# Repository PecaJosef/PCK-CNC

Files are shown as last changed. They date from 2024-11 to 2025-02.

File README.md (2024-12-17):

# PCK-CNC
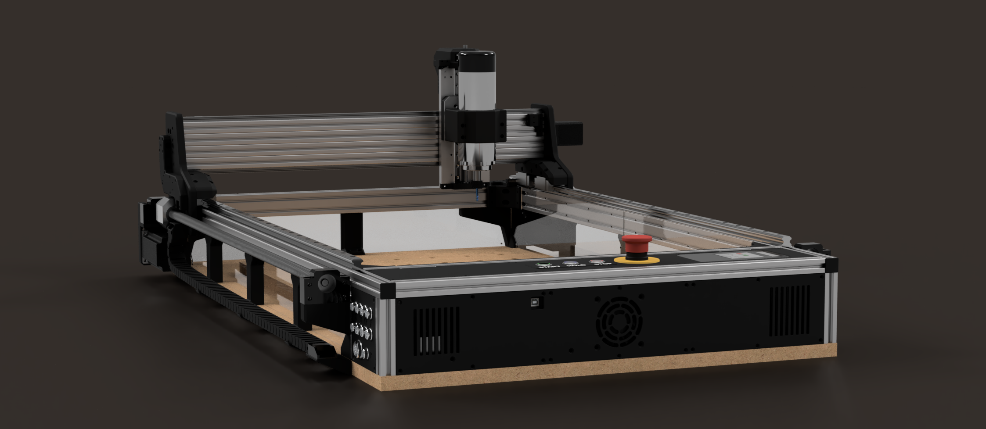
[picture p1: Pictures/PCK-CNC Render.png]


PCK-CNC is an open-source CNC router designed to offer precision, reliability, and affordability. This machine combines high-performance features with an accessible design that caters to both beginners and CNC hobbyists. Its structure is primarily 3D-printed, making it easy to build and modify, while critical components, such as aluminum parts, provide durability and strength. The router has a working area of 750mm x 490mm, making it versatile enough to handle a wide range of projects, from small hobbyist tasks to more professional-grade work.

To achieve good accuracy and reliability, the PCK-CNC utilizes ballscrews and linear rails, delivering superior precision compared to belt-driven systems. It is equipped with an 800W spindle, controlled by a Variable Frequency Drive (VFD), allowing precise adjustments to spindle speed based on the material and cutting requirements. The machine is capable of milling plastics, wood, and aluminum, ensuring it meets the needs of various users and applications.

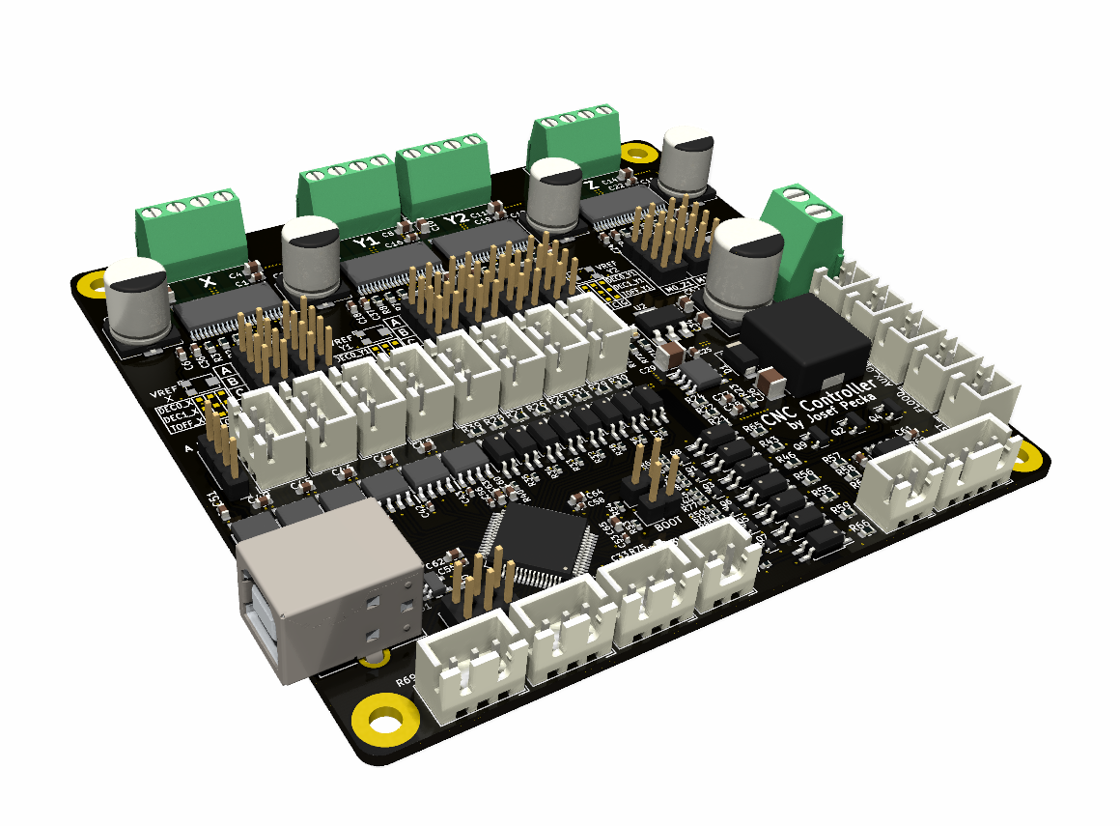
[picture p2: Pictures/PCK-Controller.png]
controller

The PCK-CNC features an integrated electronics system, saving space and making the setup more compact and user-friendly. At the heart of the system is the PCK Controller, an open-source controller designed specifically for this project. It is powered by a 32-bit microprocessor, offering smooth and fast operation, and runs on the open-source grblHAL firmware. This advanced software enables features like Y-axis auto-squaring, which improves repeatability and precision during machining.
The controller operates at 48V to manage higher motor speeds and directly interfaces with the VFD for spindle control. Safety and reliability are also priorities, the controller is galvanically isolated, protecting connected devices and computers from electrical faults. Additionally, it is designed to better withstand electromagnetic interference (EMI), ensuring stable and reliable operation.

One of the standout aspects of the PCK-CNC is its affordability. Despite its advanced features and capabilities, the machine can be built for approximately 1500 USD, making it an excellent choice for makers and hobbyists looking for a high-quality CNC router without a high price tag.
As an open-source project, PCK-CNC is open to collaboration and customization, inviting users to modify and enhance the design to suit their needs. Whether you’re starting your CNC journey or seeking a reliable platform for experimentation, the PCK-CNC provides an accessible and powerful solution for precise and efficient machining.

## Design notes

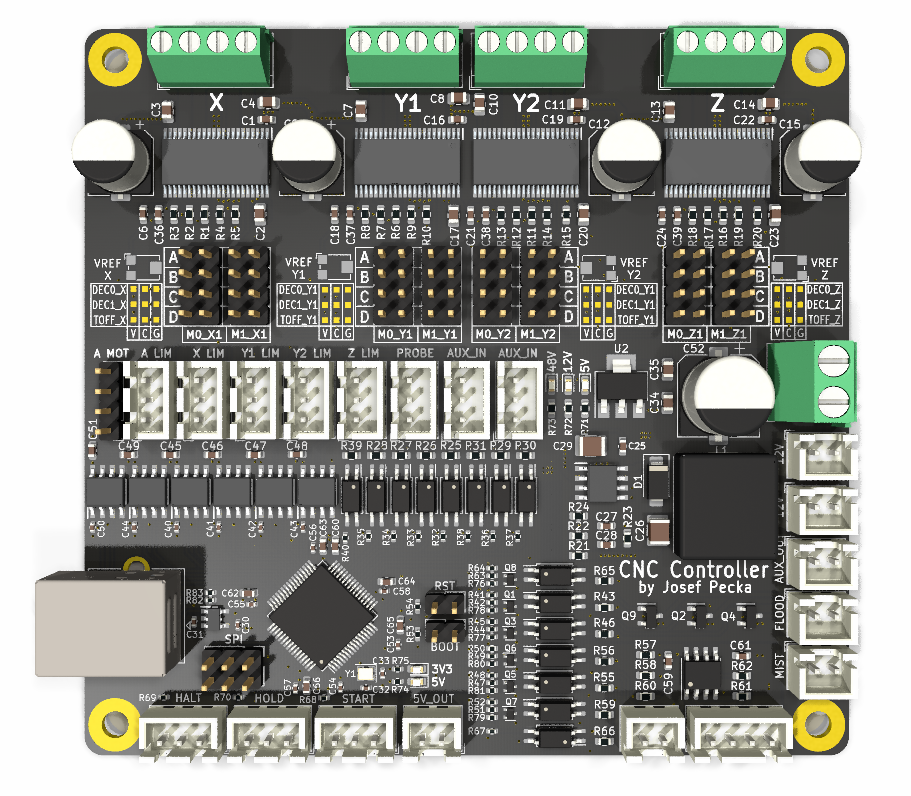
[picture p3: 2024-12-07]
Pictures/PCK-Controller top.png

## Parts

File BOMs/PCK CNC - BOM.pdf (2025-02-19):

Pcs | Extrusion size | Length | Sourcing
2 | 20x40mm | 1000mm | Best to source localy
2 | 20x40mm | 600mm
1 | 20x80mm | 670mm
1 | 20x20mm | 600mm
2 | 20x20mm | 95mm
2 | 20x20mm | 120mm
Pcs | Type | Model | Sourcing
2 | Nema 23 - 76mm | 23HE30-2804S | Stepper Online (https://www.omc-stepperonline.com/e-series-nema-23-bipolar-1-8deg-1-9nm-269oz-in-2-8a-3-2v-57x57x76mm-4-wires-23he30-2804s)
2 | Nema 17 - 48mm | 17HE19-2004S | Stepper Online (https://www.omc-stepperonline.com/e-series-nema-17-bipolar-55ncm-77-88oz-in-2a-42x48mm-4-wires-w-1m-cable-connector-17he19-2004s)
1 | Pulley GT2 60T | GT2 60T 6mm (8mm bore) | AliExpress (https://www.aliexpress.com/item/1005003165253849.html)
1 | Pulley GT2 20T | GT2 20T 6mm (5mm bore)
1 | Synchronous belt GT2 | GT2 6mm - 200mm
2 | Pulley T5 14T | T5 14T 15mm (6.35mm bore) | AliExpress (https://www.aliexpress.com/item/1005007828368485.html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)
2 | Pulley T5 14T | T5 14T 15mm (10mm bore) | AliExpress (https://www.aliexpress.com/item/1005007654749566.html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)
2 | Synchronous belt T5 | T5 15mm - 200mm | AliExpress (https://www.aliexpress.com/item/1005004695246594.html)
1 | Motor coupler | D19xL25 - 5mm - 8mm | AliExpress (https://www.aliexpress.com/item/1005004363938677.html)
Pcs | Type | Model | Sourcing
2 | Linear rail | HGR 15 - 1000mm | AliExpress (https://www.aliexpress.com/item/4000826413617.html)
4 | Linear rail block | HGH15CA
2 | Linear rail | MGN12 - 650mm | AliExpress (https://www.aliexpress.com/item/1000007480470.html)
2 | Linear rail block | MGN12H
2 | Linear rail | MGN9 - 200mm | AliExpress (https://www.aliexpress.com/item/1005002516956172.html)
4 | Linear rail block | MGN9C
2 | Ballscrew | SFU1605 - 1000mm | AliExpress (https://www.aliexpress.com/item/1005004452100727.html)
2 | Ball nut housing | DSG16H
2 | Ballscrew housing | BK12
2 | Ballscrew housing | BF12
1 | Ballscrew | SFU1204 - 650mm | AliExpress (https://www.aliexpress.com/item/1005005316105096.html)
1 | Ball nut housing | DSG12H
1 | Ballscrew housing | BK10
1 | Ballscrew housing | BF10
1 | Leadscrew - 2mm lead | T8 - 200mm | AliExpress (https://www.aliexpress.com/item/32507277503.html)
1 | Flat leadscrew nut | T8 nut | AliExpress (https://www.aliexpress.com/item/1005004574255316.html)
1 | Leadscrew housing | KFL08 8mm | AliExpress (https://www.aliexpress.com/item/1005002394517514.html)
1 | Bearing | 608ZZ | AliExpress (https://www.aliexpress.com/item/32435458212.html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)
Pcs | Type | Model | Sourcing
4 | Connector | GX12-4 | AliExpress (https://www.aliexpress.com/item/32716530720.html)
5 | Connector | GX12-2 | AliExpress (https://www.aliexpress.com/item/32716530720.html)
1 | Connector | GX20-4 | AliExpress (https://www.aliexpress.com/item/32716530720.html)
1 | Power socket | AC-04B | AliExpress (https://www.aliexpress.com/item/1005003010421047.html)
2 | Cable chain | 10x20mm - 1m | AliExpress (https://www.aliexpress.com/item/32999589537.html)
4 | Micro limit switch | KW11-3Z-B | AliExpress (https://www.aliexpress.com/item/1005006085607858.html?scm_id=1007.40050.354490.0&scm-url=1007.40050.354490.0)

Connectors & Wiring

Aluminum extrusions

Stepper motors & Belts, pulleys

Linear rails & Ballscrews, leadscrew

1 | Spindle cable | 4x1mm² (AWG20) - 3m | Best to source localy
1 | Stepper motor cables | 4x0.5mm² (AWG24) - 10m
1 | Limit switch cables | 3x0.25mm² (AWG30) - 10m
Pcs | Type | Model | Sourcing
1 | Spindle motor | VEVOR 800W - ER11 | AliExpress (https://www.aliexpress.com/item/1005007328434252.html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)
1 | VFD 1.5kW | A2-8015 | AliExpress (https://www.aliexpress.com/item/1005002865747373.html)
1 | PSU 600W 48V | LRS-600-48 | AliExpress (https://www.aliexpress.com/item/4000364274787.html)
3 | PCK Controller fan | 3010 - 12V | AliExpress (https://www.aliexpress.com/item/1005003102254928.html)
1 | Electronics fan | 7015 - 12V | AliExpress (https://www.aliexpress.com/item/1005004205974469.html)
1 | Emergency button | XB2-542 | AliExpress (https://www.aliexpress.com/item/1005001866043616.html?scm_id=1007.40050.354490.0&scm-url=1007.40050.354490.0)
3 | Button (Red,Green,Blue) | 19mm - 3-6V | AliExpress (https://www.aliexpress.com/item/1005003945292427.html)
1 | Contactor 230V 16A | 230V 16A - 2NO | AliExpress (https://www.aliexpress.com/item/4001172968682.html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)
4 | Heatsink (for PCK Controller) | 22x22x15 mm | AliExpress (https://www.aliexpress.com/item/1005004724669234.html)
Pcs | Size | Type | Sourcing
8 | M2.5x16 mm | Flat head
92 | M3x5 mm | Round head
67 | M3x8 mm | Flat head
26 | M3x8 mm | Socket head
48 | M3x10 mm | Flat head
14 | M3x10 mm | Socket head
2 | M3x12 mm | Flat head
15 | M3x16 mm | Flat head
6 | M3x20 mm | Socket head
12 | M3x25 mm | Flat head
6 | M4x6 mm | Flat head
18 | M4x8 mm | Socket head
12 | M4x10 mm | Flat head
20 | M4x10 mm | Socket head
58 | M4x12 mm | Socket head
4 | M4x16 mm | Flat head
16 | M4x16 mm | Socket head
4 | M4x20 mm | Flat head
18 | M4x40 mm | Socket head
6 | M5x8 mm | Flat head
8 | M5x10 mm | Flat head
4 | M5x20 mm | Socket head
12 | M5x25 mm | Socket head
4 | M5x30 mm | Socket head
20 | M5x50 mm | Socket head
4 | M6x70 mm | Socket head
32 | 3x20 mm wood screw | Flat head
13 | 4x20 mm wood screw | Flat head
4 | M2.5 Nut | Standart
8 | M3 Nut | Standart
16 | M4 Nut | Standart
32 | M5 Nut | Standart

Best to source localy

Electronics

Screws & nuts

4 | M6 Nut | Standart
140 | M3 T-Slot nut | 20mm Series | AliExpress (https://www.aliexpress.com/item/1005004060299402.html)
76 | M4 T-Slot nut | 20mm Series | AliExpress (https://www.aliexpress.com/item/1005004060299402.html)
42 | M3 Threaded insert | Length - 5mm | AliExpress (https://www.aliexpress.com/item/32958273559.html)
8 | M4 Threaded insert | Length - 5mm | AliExpress (https://www.aliexpress.com/item/32958273559.html)
Pcs | File name | Material | Manufacturing
2 | Acrylic sheet REAR | Acrylic | Laser/Milling
4 | Acrylic sheet SIDE | Acrylic | Laser/Milling
2 | Base mount FRONT | Aluminum | Laser/Milling
2 | Base mount rear | Aluminum | Laser/Milling
1 | Spindle mount plate | Aluminum | Milling
1 | X Axis plate LEFT | Aluminum | Milling
1 | X Axis plate RIGHT | Aluminum | Milling
1 | Z Axis back plate | Aluminum | Milling
1 | Z Axis plate | Aluminum | Milling
1 | Base mount FRONT L | PETG | 3D Printing
1 | Base mount FRONT R | PETG | 3D Printing
4 | Base mount nut cap | PLA, PETG | 3D Printing
6 | Base support | PETG | 3D Printing
1 | Cable cover | PLA, PETG | 3D Printing
1 | Control panel label | PLA, PETG | 3D Printing
9 | Electronics panel connector A | PLA, PETG | 3D Printing
7 | Electronics panel connector B | PLA, PETG | 3D Printing
1 | Electronics panel connector C | PLA, PETG | 3D Printing
16 | Electronics panel corner connector | PLA, PETG | 3D Printing
1 | Electronics panel FRONT L | PLA, PETG | 3D Printing
1 | Electronics panel FRONT M | PLA, PETG | 3D Printing
1 | Electronics panel FRONT R | PLA, PETG | 3D Printing
1 | Electronics panel LEFT | PLA, PETG | 3D Printing
1 | Electronics panel REAR L | PLA, PETG | 3D Printing
1 | Electronics panel REAR R | PLA, PETG | 3D Printing
1 | Electronics panel RIGHT | PLA, PETG | 3D Printing
1 | Electronics panel TOP L | PLA, PETG | 3D Printing
1 | Electronics panel TOP M | PLA, PETG | 3D Printing
1 | Electronics panel TOP R | PLA, PETG | 3D Printing
4 | Frame corner connector | PETG | 3D Printing
1 | PCK CNC Controller mount | PLA, PETG | 3D Printing
1 | PSU Mounting plate A | PLA, PETG | 3D Printing
1 | PSU Mounting plate B | PLA, PETG | 3D Printing
1 | PSu Mounting plate BOT | PLA, PETG | 3D Printing
1 | Spindle mount | PETG | 3D Printing
1 | X Axis ballscrew mount LEFT | PETG | 3D Printing
1 | X Axis ballscrew mount RIGHT | PETG | 3D Printing
1 | X Axis cable chain mount | PLA, PETG | 3D Printing
1 | X Axis cable chain support | PLA, PETG | 3D Printing
1 | X Axis end stop mount | PLA, PETG | 3D Printing
1 | X Axis linear rail mount | PETG | 3D Printing
1 | X Axis motor mount | PETG | 3D Printing

Mechanical parts

1 | Y Axis cable chain mount B | PLA, PETG | 3D Printing
1 | Y Axis cable chain mount F | PLA, PETG | 3D Printing
3 | Y Axis cable chain support | PLA, PETG | 3D Printing
1 | Y Axis end stop mount LEFT | PLA, PETG | 3D Printing
1 | Y Axis end stop mount RIGHT | PLA, PETG | 3D Printing
1 | Y Axis linear rail mount LEFT | PETG | 3D Printing
1 | Y Axis linear rail mount RIGHT | PETG | 3D Printing
1 | Y Axis motor mount LEFT | PETG | 3D Printing
1 | Y Axis motor mount RIGHT | PETG | 3D Printing
1 | Z Axis cover | PLA, PETG | 3D Printing
1 | Z Axis endstop mount | PLA, PETG | 3D Printing
1 | Z Axis leadscrew bearing mount TOP | PETG | 3D Printing
1 | Z Axis leadscrew bearing mount | PETG | 3D Printing
1 | Z Axis linear rails mount | PETG | 3D Printing
1 | Z Axis motor holder | PETG | 3D Printing
Pcs | File name | Size | Sourcing
1 | MDF Base board | 1125x640x20mm | Best to source localy
1 | MDF Spoil board | 760x490x18mm

MDF Boards

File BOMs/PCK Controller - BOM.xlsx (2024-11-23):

Item | Qty | Reference(s) | Value | LibPart | Footprint | Datasheet | DNP | Description | Height | Manufacturer_Name | Manufacturer_Part_Number | Mouser Part Number | Mouser Price/Stock | Sim.Device | Sim.Pins
1 | 7 | 12V1, 12V2, AUX1, ESTOP1, FLOOD1, MIST1, PWR1 | Conn_01x02 | Connector_Generic:Conn_01x02 | Connector_JST:JST_XH_B2B-XH-A_1x02_P2.50mm_Vertical | ~
2 | 1 | A_LIM1 | A_Lim | Connector_Generic:Conn_01x03 | Connector_JST:JST_XH_B3B-XH-A_1x03_P2.50mm_Vertical | ~
3 | 1 | AUX_IN1 | ESTOP | Connector_Generic:Conn_01x03 | Connector_JST:JST_XH_B3B-XH-A_1x03_P2.50mm_Vertical | ~
4 | 1 | AUX_IN2 | Door | Connector_Generic:Conn_01x03 | Connector_JST:JST_XH_B3B-XH-A_1x03_P2.50mm_Vertical | ~
5 | 1 | BOOT1 | BOOT | Connector_Generic:Conn_01x02 | Connector_PinHeader_2.54mm:PinHeader_1x02_P2.54mm_Vertical | ~
6 | 5 | C1, C16, C19, C22, C61 | 1uF/16V | Device:C | Capacitor_SMD:C_0603_1608Metric | ~
7 | 4 | C2, C17, C20, C23 | 0.1uF/63V | Device:C | Capacitor_SMD:C_0805_2012Metric | ~
8 | 2 | C3, C4 | 10nF/63V | Device:C | Capacitor_SMD:C_0805_2012Metric | ~
9 | 4 | C5, C9, C12, C15 | 47uF/63V | Device:C_Polarized | Capacitor_SMD:CP_Elec_8x10 | ~
10 | 4 | C6, C18, C21, C24 | 1uF/6.3V | Device:C | Capacitor_SMD:C_0603_1608Metric | ~
11 | 6 | C7, C8, C10, C11, C13, C14 | 0.01uF/63V | Device:C | Capacitor_SMD:C_0805_2012Metric | ~
12 | 1 | C25 | 100nF/10V | Device:C | Capacitor_SMD:C_0603_1608Metric | ~
13 | 1 | C26 | 47uF/25V | Device:C | Capacitor_SMD:C_1210_3225Metric | ~
14 | 1 | C27 | 100pF | Device:C | Capacitor_SMD:C_0603_1608Metric | ~
15 | 1 | C28 | 15nF | Device:C | Capacitor_SMD:C_0603_1608Metric | ~
16 | 1 | C29 | 2.2uF/63V | Device:C | Capacitor_SMD:C_1210_3225Metric | ~
17 | 2 | C30, C31 | 1uF/6.3V | Device:C | Capacitor_SMD:C_0402_1005Metric | ~
18 | 2 | C32, C33 | 10pF | Device:C | Capacitor_SMD:C_0402_1005Metric | ~
19 | 1 | C34 | 10uF/25V | Device:C | Capacitor_SMD:C_0805_2012Metric | ~
20 | 1 | C35 | 10uF/10V | Device:C | Capacitor_SMD:C_0805_2012Metric | ~
21 | 4 | C36, C37, C38, C39 | 0.1uF/10V | Device:C | Capacitor_SMD:C_0603_1608Metric | ~
22 | 6 | C40, C41, C42, C43, C44, C50 | 0.1uF/6.3V | Device:C | Capacitor_SMD:C_0402_1005Metric | ~
23 | 6 | C45, C46, C47, C48, C49, C51 | 0.1uF/6.3V | Device:C | Capacitor_SMD:C_0603_1608Metric | ~
24 | 1 | C52 | 100u/63V | Device:C_Polarized | Capacitor_SMD:CP_Elec_10x12.5 | ~
25 | 6 | C53, C54, C55, C56, C57, C58 | 100n | Device:C | Capacitor_SMD:C_0402_1005Metric | ~
26 | 1 | C59 | 1u/16V | Device:C | Capacitor_SMD:C_0603_1608Metric | ~
27 | 1 | C60 | 4.7uF/6.3V | Device:C | Capacitor_SMD:C_0603_1608Metric | ~
28 | 5 | C62, C63, C64, C65, C66 | 1u | Device:C | Capacitor_SMD:C_0603_1608Metric | ~
29 | 1 | D1 | 3.5A | Device:D | Diode_SMD:D_SMA | ~ |  |  |  |  |  |  |  | D | 1=K 2=A
30 | 5 | D2, D3, D4, D5, D6 | LED | Device:LED | LED_SMD:LED_0603_1608Metric | ~
31 | 4 | H1, H2, H3, H4 | MountingHole_Pad | Mechanical:MountingHole_Pad | MountingHole:MountingHole_3.5mm_Pad | ~
32 | 4 | IC1, IC2, IC3, IC4 | DRV8462DDWR_X | SamacSys_Parts:DRV8462DDWR | SamacSys_Parts:SOP64P810X120-45N | https://www.ti.com/lit/gpn/drv8462 |  | Motor / Motion / Ignition Controllers & Drivers 65-V, 10-A, dual H-bridge stepper motor driver with smart tune, stall detect and auto-torque | 2024-02-01 | Texas Instruments | DRV8462DDWR | 595-DRV8462DDWR | https://www.mouser.co.uk/ProductDetail/Texas-Instruments/DRV8462DDWR?qs=rQFj71Wb1eVexvYNsDfnvA%3D%3D
33 | 1 | IC5 | TPS54360BDDAR | SamacSys_Parts:TPS54360BDDAR | SamacSys_Parts:SOIC127P600X170-9N | http://www.ti.com/lit/gpn/TPS54360B |  | 60-V input, 3.5-A, step-down DC/DC converter with Eco-Mode | 2024-07-01 | Texas Instruments | TPS54360BDDAR | 595-TPS54360BDDAR | https://www.mouser.co.uk/ProductDetail/Texas-Instruments/TPS54360BDDAR?qs=l7cgNqFNU1iKlQpZ394odQ%3D%3D
34 | 6 | IC6, IC7, IC8, IC9, IC10, IC12 | ISO6720FBDR | SamacSys_Parts:ISO6720FBDR | SamacSys_Parts:SOIC127P600X175-8N | https://www.ti.com/lit/ds/symlink/iso6720.pdf?ts=1631770491208 |  | Digital Isolators General purpose dual-channel, 2/0, digital isolator | 1975-01-01 | Texas Instruments | ISO6720FBDR | 595-ISO6720FBDR | https://www.mouser.co.uk/ProductDetail/Texas-Instruments/ISO6720FBDR?qs=QNEnbhJQKva93m6DsjFZMw%3D%3D
35 | 1 | IC11 | TLV75533PDBVR | SamacSys_Parts:TLV75533PDBVR | SamacSys_Parts:SOT95P280X145-5N | http://www.ti.com/lit/gpn/tlv755p |  | LDO Voltage Regulators 500-mA, Low IQ, Small Size, Low Dropout Regulator 5-SOT-23 -40 to 125 | 1945-01-01 | Texas Instruments | TLV75533PDBVR | 595-TLV75533PDBVR | https://www.mouser.co.uk/ProductDetail/Texas-Instruments/TLV75533PDBVR?qs=55YtniHzbhAKEwqeO2xJXQ%3D%3D
36 | 1 | J1 | 48V_IN | Connector:Screw_Terminal_01x02 | TerminalBlock_Phoenix:TerminalBlock_Phoenix_MKDS-1,5-2_1x02_P5.00mm_Horizontal | ~
37 | 1 | J2 | Conn_01x04 | Connector_Generic:Conn_01x04 | Connector_JST:JST_XH_B4B-XH-A_1x04_P2.50mm_Vertical | (symbol "Connector_Generic:Conn_01x04" (pin_names (offset 1.016) hide) (in_bom yes) (on_board yes)
38 | 4 | J3, J19, J30, J41 | TOFF_VCC | Connector:Conn_01x01_Pin | PADs:Pad_0.75x0.75mm_borderless | ~
39 | 4 | J4, J20, J31, J42 | TOFF_COM | Connector:Conn_01x01_Pin | PADs:Pad_0.75x0.75mm_borderless | ~
40 | 4 | J5, J21, J32, J43 | TOFF_GND | Connector:Conn_01x01_Pin | PADs:Pad_0.75x0.75mm_borderless | ~
41 | 4 | J6, J7, J8, J9 | Screw_Terminal_01x04 | Connector:Screw_Terminal_01x04 | TerminalBlock_4Ucon:TerminalBlock_4Ucon_1x04_P3.50mm_Horizontal | ~
42 | 4 | J10, J22, J33, J44 | DEC0_VCC | Connector:Conn_01x01_Pin | PADs:Pad_0.75x0.75mm_borderless | ~
43 | 4 | J11, J23, J34, J45 | DEC0_COM | Connector:Conn_01x01_Pin | PADs:Pad_0.75x0.75mm_borderless | ~
44 | 4 | J12, J24, J35, J46 | DEC0_GND | Connector:Conn_01x01_Pin | PADs:Pad_0.75x0.75mm_borderless | ~
45 | 4 | J13, J25, J36, J47 | DEC1_VCC | Connector:Conn_01x01_Pin | PADs:Pad_0.75x0.75mm_borderless | ~
46 | 4 | J14, J26, J37, J48 | DEC1_COM | Connector:Conn_01x01_Pin | PADs:Pad_0.75x0.75mm_borderless | ~
47 | 4 | J15, J27, J38, J49 | DEC1_GND | Connector:Conn_01x01_Pin | PADs:Pad_0.75x0.75mm_borderless | ~
48 | 1 | J16 | Conn_01x04 | Connector_Generic:Conn_01x04 | Connector_PinHeader_2.54mm:PinHeader_1x04_P2.54mm_Vertical | ~
49 | 1 | J18 | Conn_01x06 | Connector_Generic:Conn_01x06 | Connector_PinHeader_2.54mm:PinHeader_2x03_P2.54mm_Vertical | ~
50 | 1 | L1 | 22uH | Device:L | Inductor_SMD:L_12x12mm_H8mm | ~
51 | 4 | M0_X1, M0_Y1, M0_Y2, M0_Z1 | M0 | Connector_Generic:Conn_02x04_Odd_Even | Connector_PinHeader_2.54mm:PinHeader_2x04_P2.54mm_Vertical | ~
52 | 4 | M1_X1, M1_Y1, M1_Y2, M1_Z1 | M1 | Connector_Generic:Conn_02x04_Odd_Even | Connector_PinHeader_2.54mm:PinHeader_2x04_P2.54mm_Vertical | ~
53 | 1 | PAUSE1 | Pause | Connector_Generic:Conn_01x03 | Connector_JST:JST_XH_B3B-XH-A_1x03_P2.50mm_Vertical | ~
54 | 1 | PROBE1 | Probe | Connector_Generic:Conn_01x03 | Connector_JST:JST_XH_B3B-XH-A_1x03_P2.50mm_Vertical | ~
55 | 6 | Q1, Q3, Q5, Q6, Q7, Q8 | DMG1012T | Transistor_FET:DMG1012T | Package_TO_SOT_SMD:SOT-523 | https://www.diodes.com/assets/Datasheets/ds31783.pdf
56 | 3 | Q2, Q4, Q9 | DMN6075S | Transistor_FET:DMN6075S | Package_TO_SOT_SMD:SOT-23 | http://www.diodes.com/assets/Datasheets/DMN6075S.pdf
57 | 1 | R0 | 0R | Device:R | Resistor_SMD:R_0603_1608Metric | ~
58 | 19 | R1, R2, R3, R6, R7, R8, R11, R12, R13, R16, R17, R18, R22, R43, R46, R57, R58, R61, R65 | 10k | Device:R | Resistor_SMD:R_0603_1608Metric | ~
59 | 8 | R4, R5, R9, R10, R14, R15, R19, R20 | 330k | Device:R | Resistor_SMD:R_0603_1608Metric | ~
60 | 1 | R21 | 140k | Device:R | Resistor_SMD:R_0603_1608Metric | ~
61 | 1 | R23 | 12,1k | Device:R | Resistor_SMD:R_0603_1608Metric | ~
62 | 1 | R24 | 187k | Device:R | Resistor_SMD:R_0603_1608Metric | ~
63 | 10 | R25, R26, R27, R28, R29, R30, R31, R39, R66, R71 | 1k | Device:R | Resistor_SMD:R_0603_1608Metric | ~
64 | 17 | R32, R33, R34, R35, R36, R37, R38, R40, R67, R74, R75, R76, R77, R78, R79, R80, R81 | 1k | Device:R | Resistor_SMD:R_0402_1005Metric | ~
65 | 6 | R41, R45, R48, R50, R52, R64 | 470R | Device:R | Resistor_SMD:R_0402_1005Metric | ~
66 | 9 | R42, R44, R47, R49, R51, R63, R68, R69, R70 | 10k | Device:R | Resistor_SMD:R_0402_1005Metric | ~
67 | 2 | R53, R54 | 10k | Device:R | Resistor_SMD:R_0402_1005Metric_Pad0.72x0.64mm_HandSolder | ~
68 | 2 | R55, R56 | 1K | Device:R | Resistor_SMD:R_0603_1608Metric | ~
69 | 3 | R59, R60, R72 | 4k7 | Device:R | Resistor_SMD:R_0603_1608Metric | ~
70 | 1 | R62 | 100k | Device:R | Resistor_SMD:R_0603_1608Metric | ~
71 | 1 | R73 | 22k (10k) | Device:R | Resistor_SMD:R_0603_1608Metric | ~
72 | 2 | R82, R83 | 22R | Device:R | Resistor_SMD:R_0402_1005Metric | ~
73 | 1 | RST1 | RST | Connector_Generic:Conn_01x02 | Connector_PinHeader_2.54mm:PinHeader_1x02_P2.54mm_Vertical | ~
74 | 4 | RV1, RV2, RV3, RV4 | 30k | Device:R_Potentiometer | Potentiometer_SMD:Potentiometer_Bourns_TC33X_Vertical | ~
75 | 1 | START1 | Start | Connector_Generic:Conn_01x03 | Connector_JST:JST_XH_B3B-XH-A_1x03_P2.50mm_Vertical | ~
76 | 1 | STOP1 | Stop | Connector_Generic:Conn_01x03 | Connector_JST:JST_XH_B3B-XH-A_1x03_P2.50mm_Vertical | ~
77 | 1 | U1 | STM32F446RETx | MCU_ST_STM32F4:STM32F446RETx | Package_QFP:LQFP-64_10x10mm_P0.5mm | https://www.st.com/resource/en/datasheet/stm32f446re.pdf
78 | 1 | U2 | NCP1117-5.0_SOT223 | Regulator_Linear:NCP1117-5.0_SOT223 | Package_TO_SOT_SMD:SOT-223-3_TabPin2 | http://www.onsemi.com/pub_link/Collateral/NCP1117-D.PDF
79 | 15 | U3, U4, U5, U6, U7, U8, U9, U10, U12, U13, U14, U15, U16, U17, U18 | TLP293 | Isolator:TLP291 | Package_SO:SOIC-4_4.55x2.6mm_P1.27mm | https://toshiba.semicon-storage.com/info/docget.jsp?did=12884&prodName=TLP291
80 | 1 | U11 | LM358 | Amplifier_Operational:LM358 | Package_SO:SOIC-8_3.9x4.9mm_P1.27mm | http://www.ti.com/lit/ds/symlink/lm2904-n.pdf
81 | 1 | USB1 | USB_B | Connector:USB_B | NEW_USB:USB_B_OST_USB-B1HSxx_Horizontal_NEW | ~
82 | 1 | X_LIM1 | X_Lim | Connector_Generic:Conn_01x03 | Connector_JST:JST_XH_B3B-XH-A_1x03_P2.50mm_Vertical | ~
83 | 1 | Y1 | 25MHz/10pF | Device:Crystal_GND24 | Crystal:Crystal_SMD_2016-4Pin_2.0x1.6mm | ~
84 | 1 | Y1_LIM1 | Y1_Lim | Connector_Generic:Conn_01x03 | Connector_JST:JST_XH_B3B-XH-A_1x03_P2.50mm_Vertical | ~
85 | 1 | Y2_LIM1 | Y2_Lim | Connector_Generic:Conn_01x03 | Connector_JST:JST_XH_B3B-XH-A_1x03_P2.50mm_Vertical | ~
86 | 1 | Z_LIM1 | Z_Lim | Connector_Generic:Conn_01x03 | Connector_JST:JST_XH_B3B-XH-A_1x03_P2.50mm_Vertical | ~

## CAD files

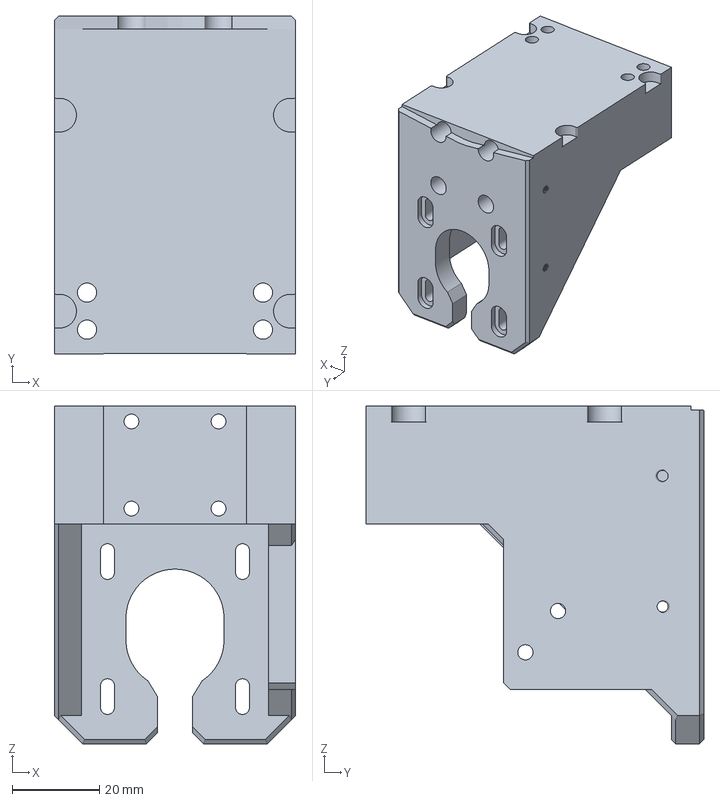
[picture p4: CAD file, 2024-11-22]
3D Printed parts/3MF Files/Z Axis motor holder.3mf
55.4 x 77.6 x 77.5 mm

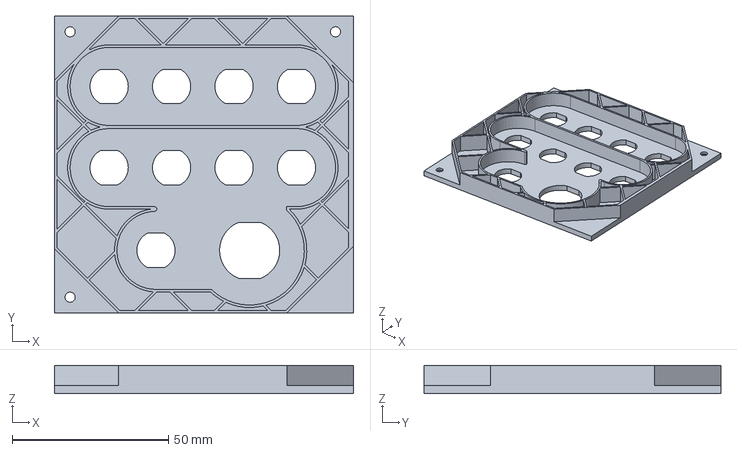
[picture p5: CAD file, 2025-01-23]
3D Printed parts/STEP Files/Electronics panel LEFT.step
95.8 x 95.0 x 9.00 mm

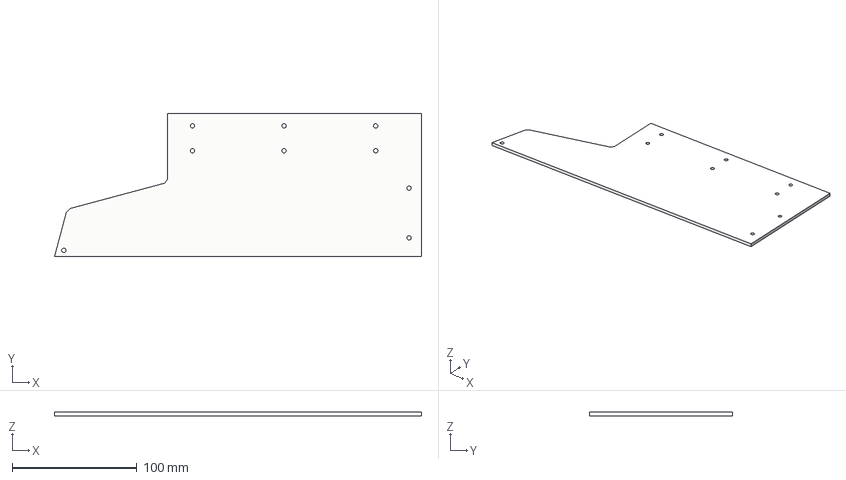
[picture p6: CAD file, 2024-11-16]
Acrylic sheets/STEP Files/Acrylic sheet REAR.step
294.8 x 115.0 x 3.00 mm

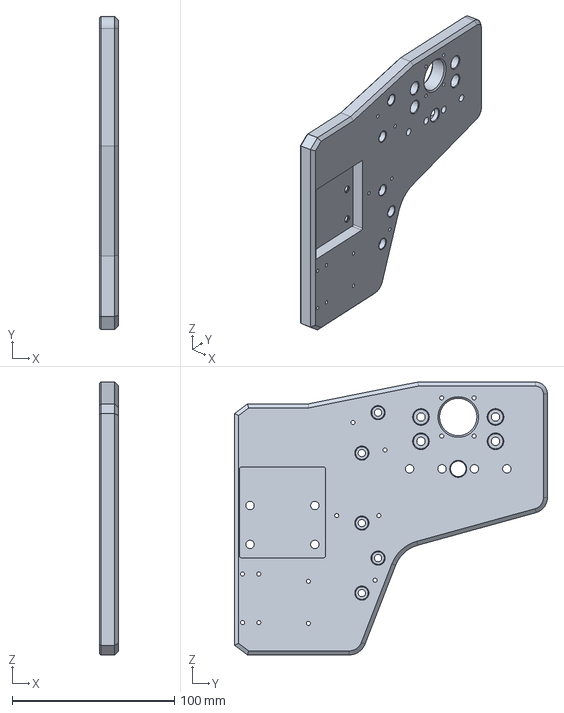
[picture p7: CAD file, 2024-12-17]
Aluminum parts/STEP Files/X Axis plate LEFT.step
12.0 x 193.2 x 168.5 mm

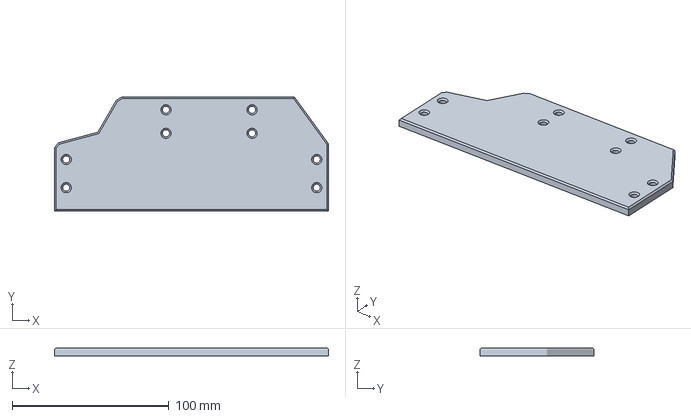
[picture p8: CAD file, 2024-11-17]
3D Printed parts/3MF Files/PSU Mounting plate B.3mf
175.0 x 73.0 x 5.25 mm

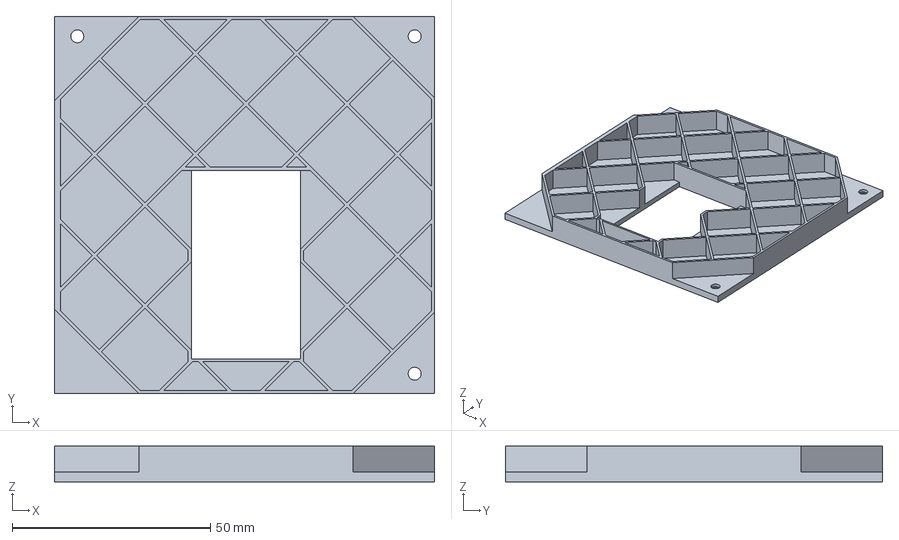
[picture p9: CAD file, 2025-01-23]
3D Printed parts/STEP Files/Electronics panel RIGHT.step
95.8 x 95.0 x 9.00 mm

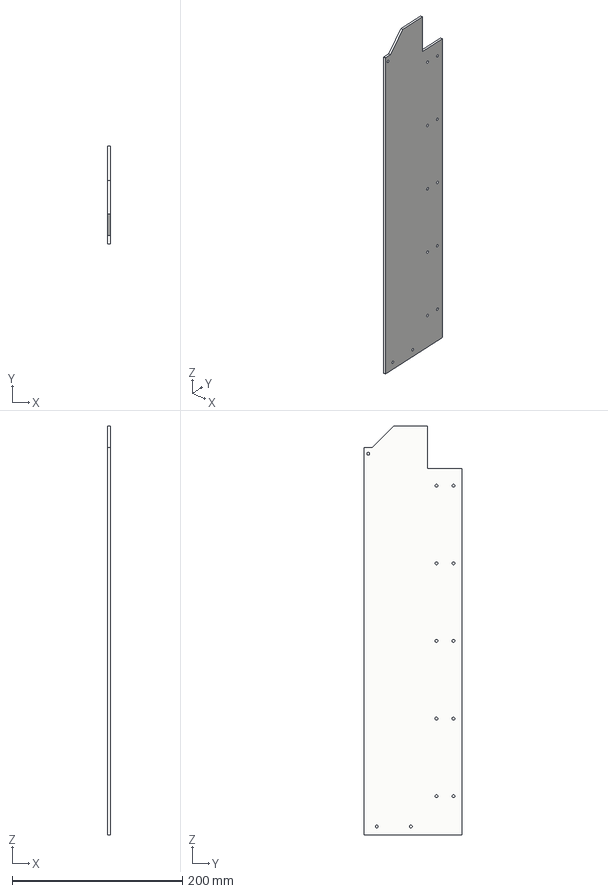
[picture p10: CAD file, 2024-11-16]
Acrylic sheets/STEP Files/Acrylic sheet SIDE.step
3.00 x 115.0 x 479.8 mm

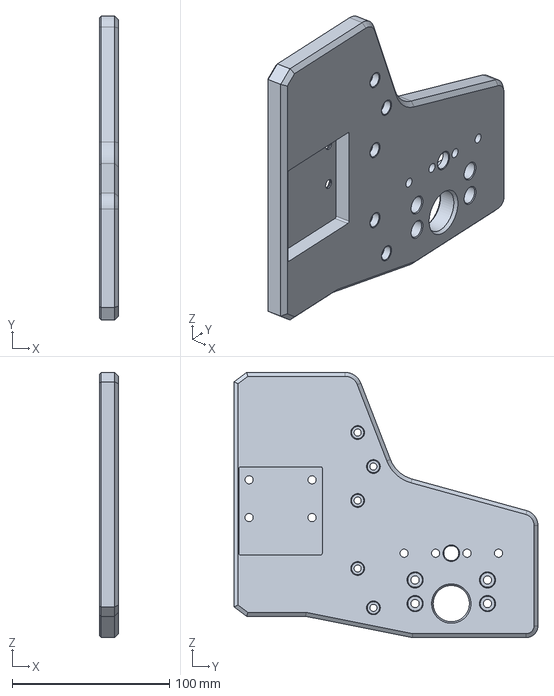
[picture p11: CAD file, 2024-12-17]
Aluminum parts/STEP Files/X Axis plate RIGHT.step
12.0 x 193.2 x 168.5 mm

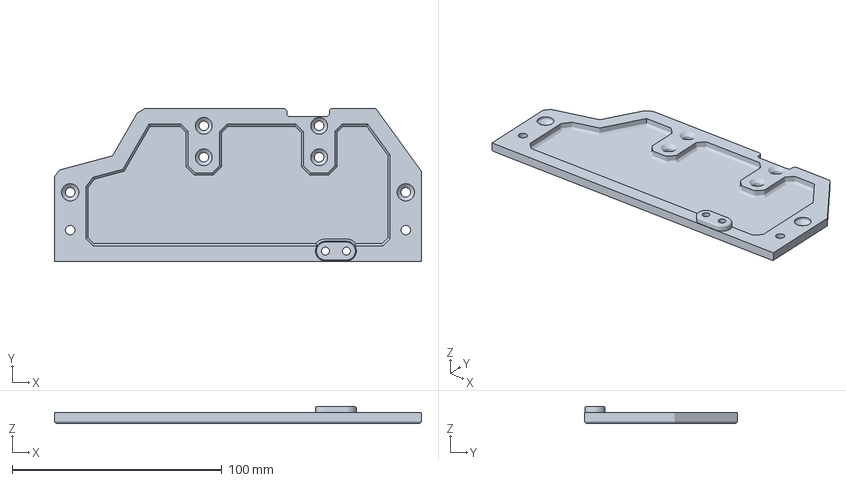
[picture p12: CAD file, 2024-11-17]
3D Printed parts/3MF Files/PSU Mounting plate A.3mf
175.0 x 73.0 x 8.25 mm

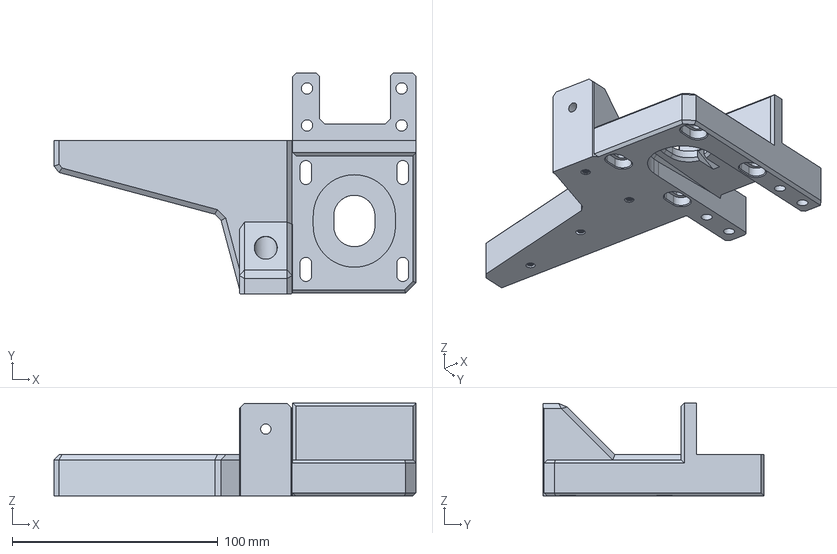
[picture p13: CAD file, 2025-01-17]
3D Printed parts/STEP Files/Y Axis motor mount RIGHT.step
176.1 x 107.5 x 45.1 mm

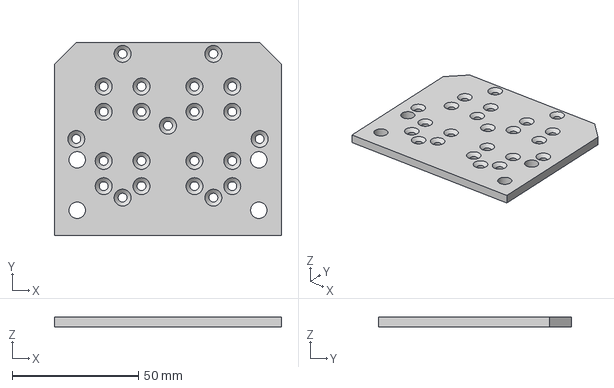
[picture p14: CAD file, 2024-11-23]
Aluminum parts/STEP Files/Spindle mount plate.step
90.0 x 76.5 x 4.00 mm

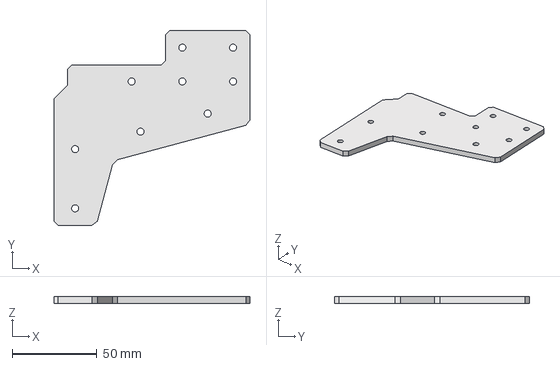
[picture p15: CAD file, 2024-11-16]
Aluminum parts/STEP Files/Base mount FRONT.step
115.9 x 115.0 x 4.00 mm

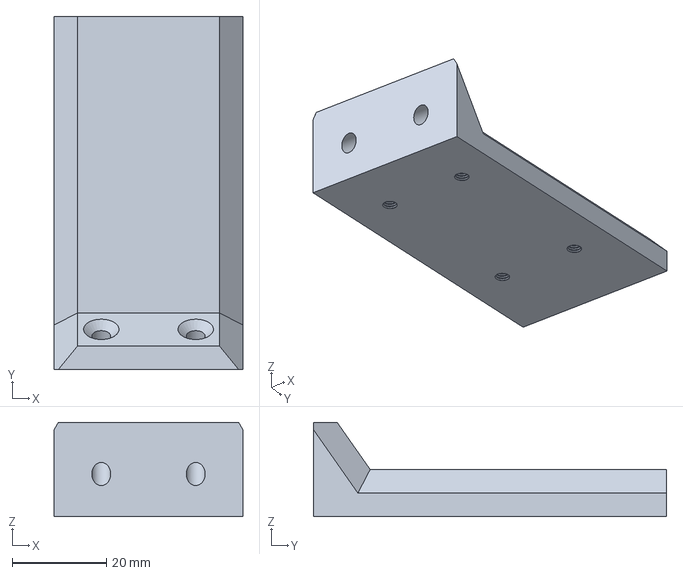
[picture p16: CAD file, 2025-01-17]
3D Printed parts/STEP Files/Base support REAR.step
40.0 x 74.8 x 20.0 mm

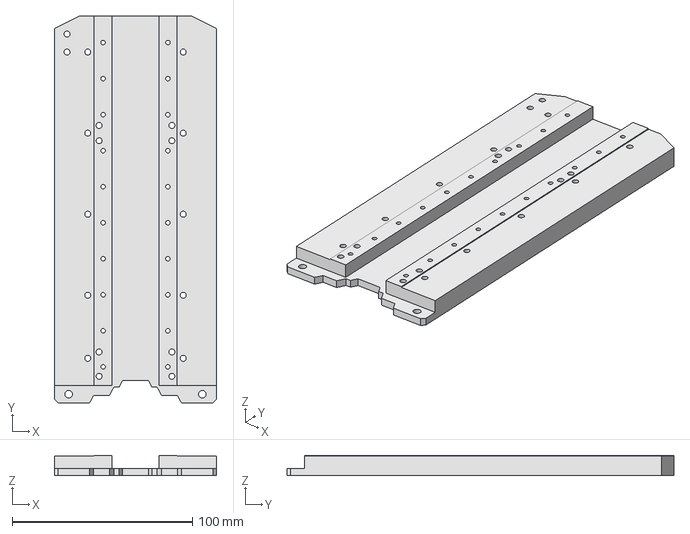
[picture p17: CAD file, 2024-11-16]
Aluminum parts/STEP Files/Z Axis plate.step
90.0 x 214.8 x 11.4 mm

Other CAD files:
3D Printed parts/STEP Files/Y Axis motor mount LEFT.step
3D Printed parts/STEP Files/Z Axis motor mount.step
Aluminum parts/STEP Files/Base mount REAR.step
3D Printed parts/STEP Files/Z Axis cover.step
3D Printed parts/3MF Files/Base mount FRONT L.3mf
3D Printed parts/3MF Files/Base mount FRONT R.3mf
3D Printed parts/3MF Files/Base mount nut cap.3mf
3D Printed parts/3MF Files/Base support REAR.3mf
3D Printed parts/3MF Files/Base support.3mf
3D Printed parts/3MF Files/Cable cover.3mf
3D Printed parts/3MF Files/Control panel label.3mf
3D Printed parts/3MF Files/Electronics panel FRONT L.3mf
3D Printed parts/3MF Files/Electronics panel FRONT M.3mf
3D Printed parts/3MF Files/Electronics panel FRONT R.3mf
3D Printed parts/3MF Files/Electronics panel LEFT.3mf
3D Printed parts/3MF Files/Electronics panel REAR L.3mf
3D Printed parts/3MF Files/Electronics panel REAR R.3mf
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

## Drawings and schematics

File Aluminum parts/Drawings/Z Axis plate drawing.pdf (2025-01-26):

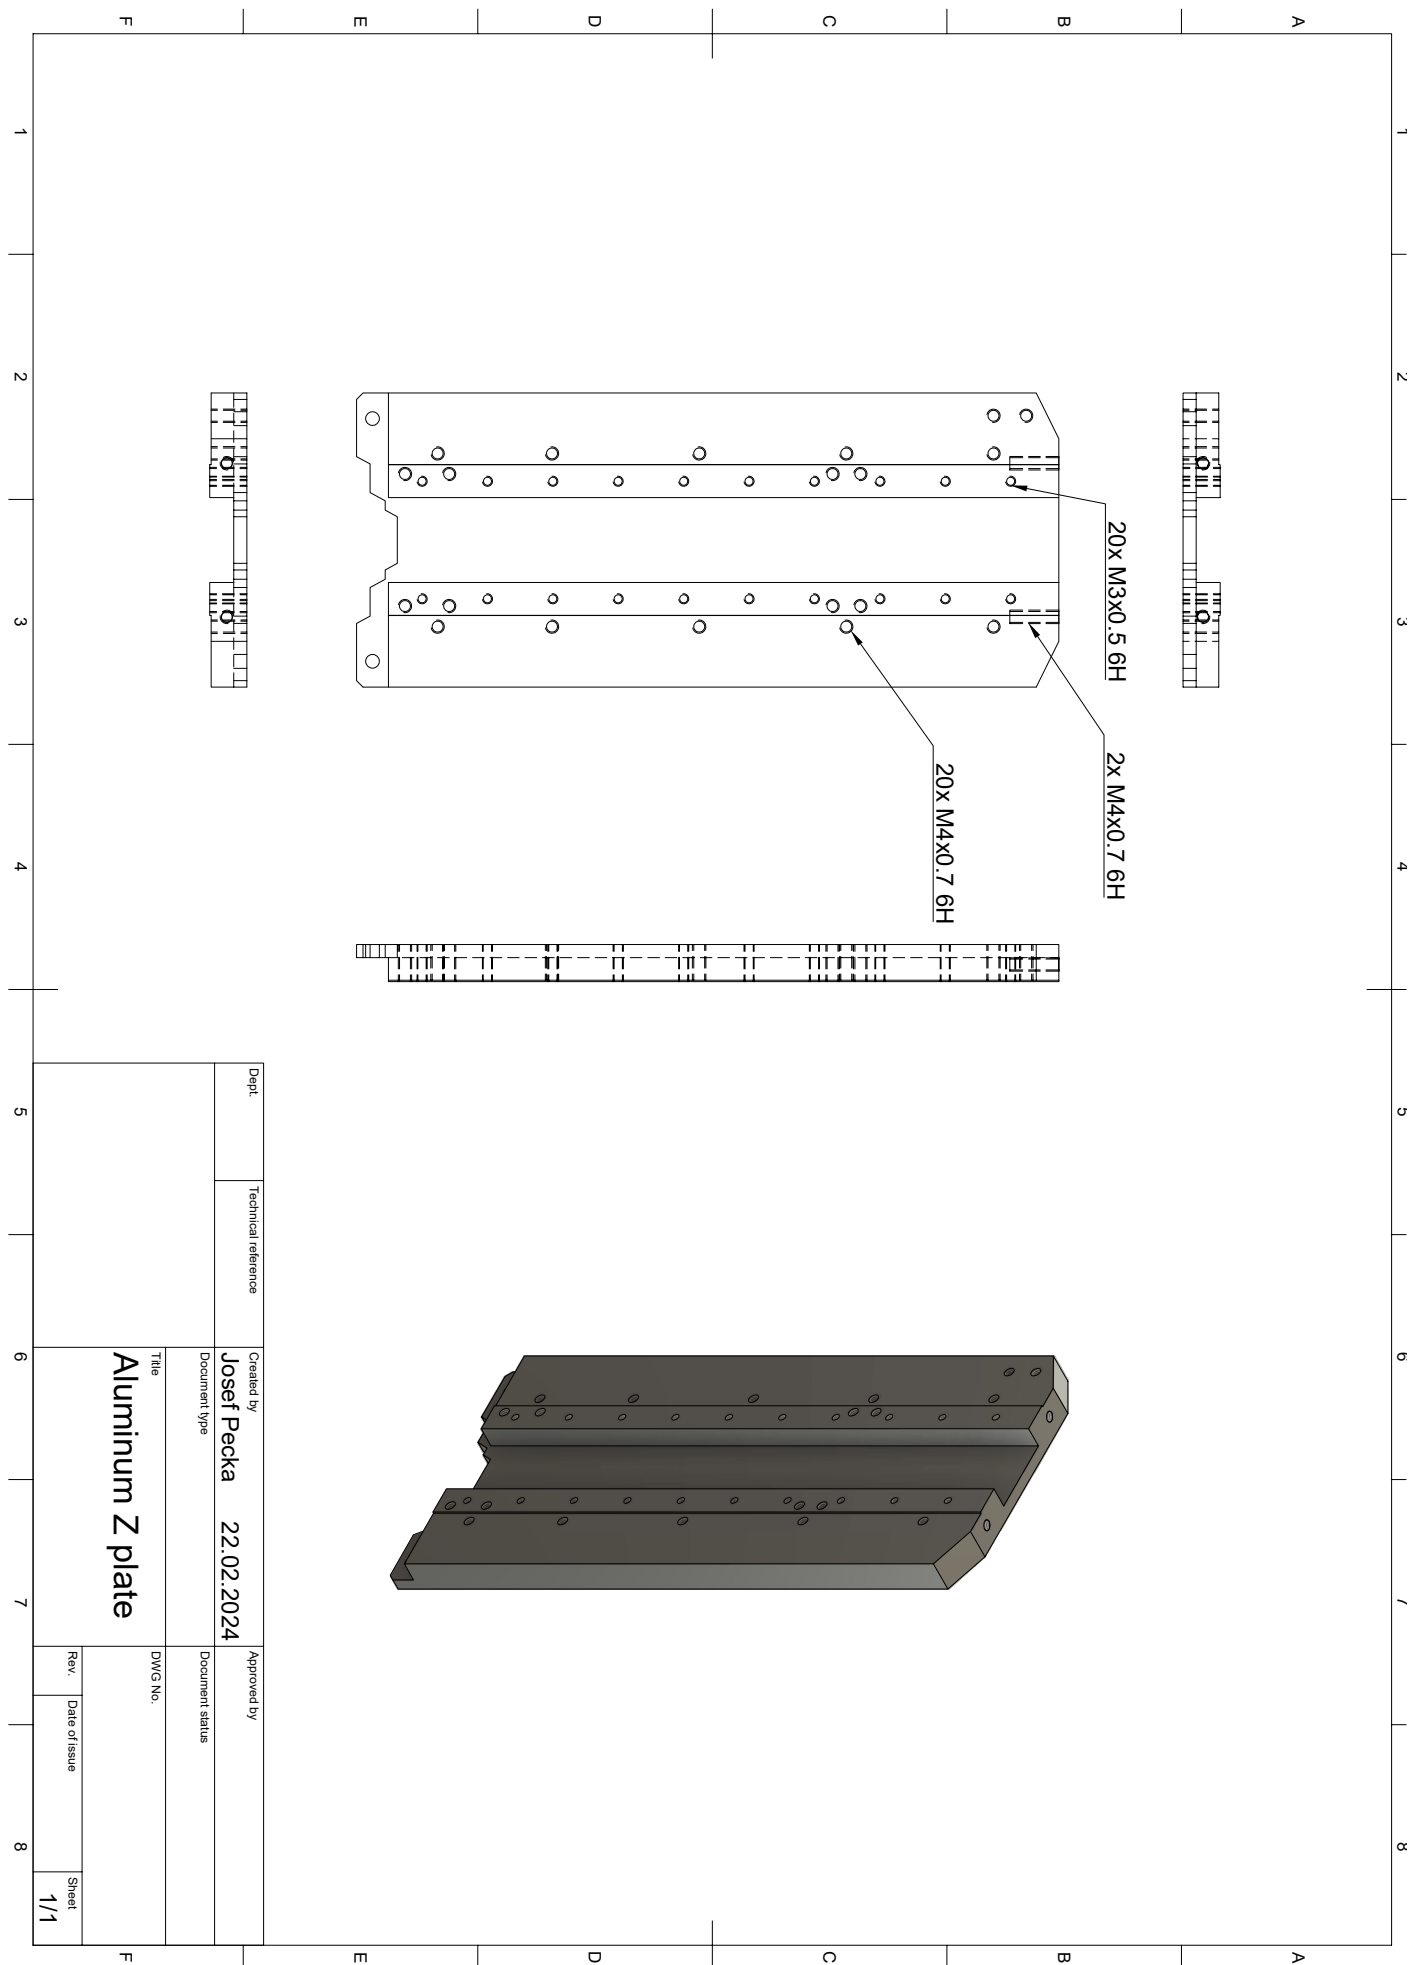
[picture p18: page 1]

1 A 2 3 4 5 6 7 8 1 2 3 4 5 6 7 8 FEDCB FEDCBA Dept. Technical reference Created by Approved by Title DWG No. Document type Document status Rev. Date of issue Sheet 22.02.2024 1/1 Aluminum Z plate Josef Pecka 20x M3x0.5 6H 2x M4x0.7 6H 20x M4x0.7 6H

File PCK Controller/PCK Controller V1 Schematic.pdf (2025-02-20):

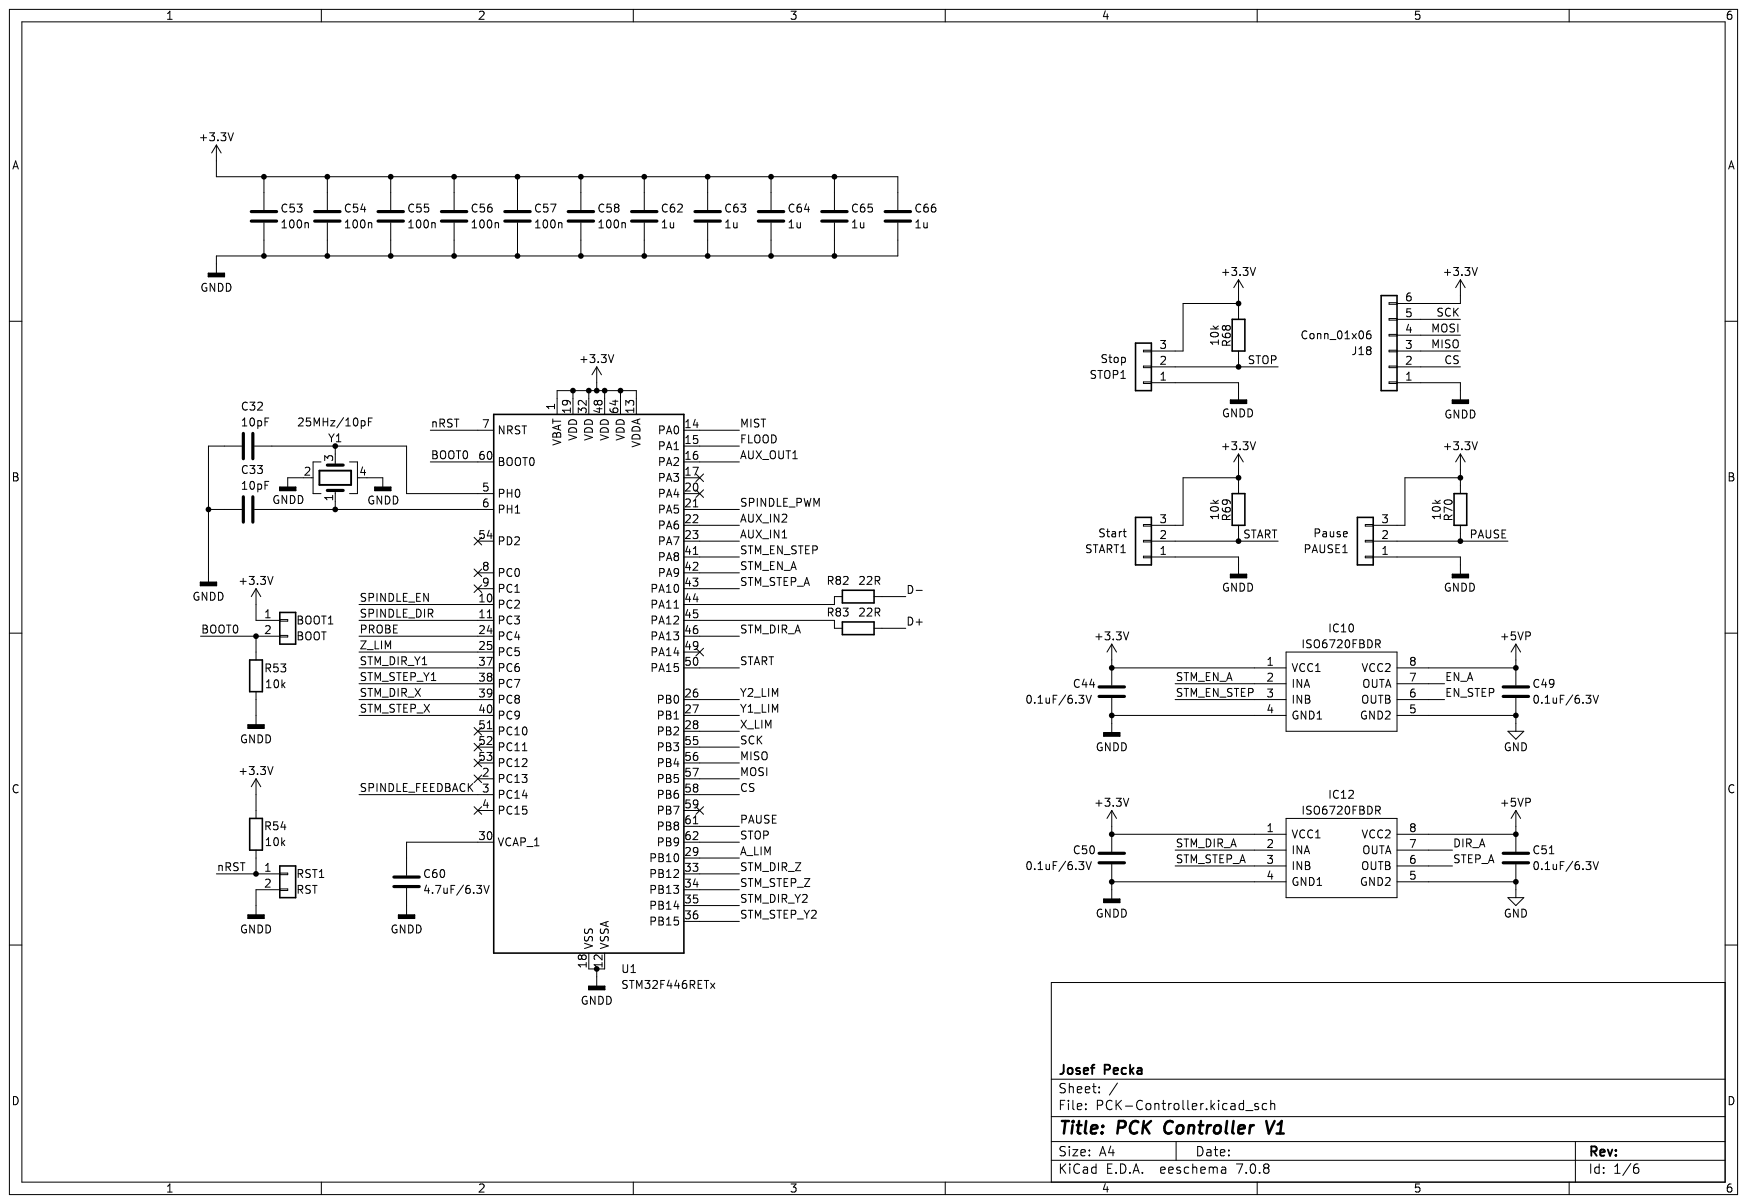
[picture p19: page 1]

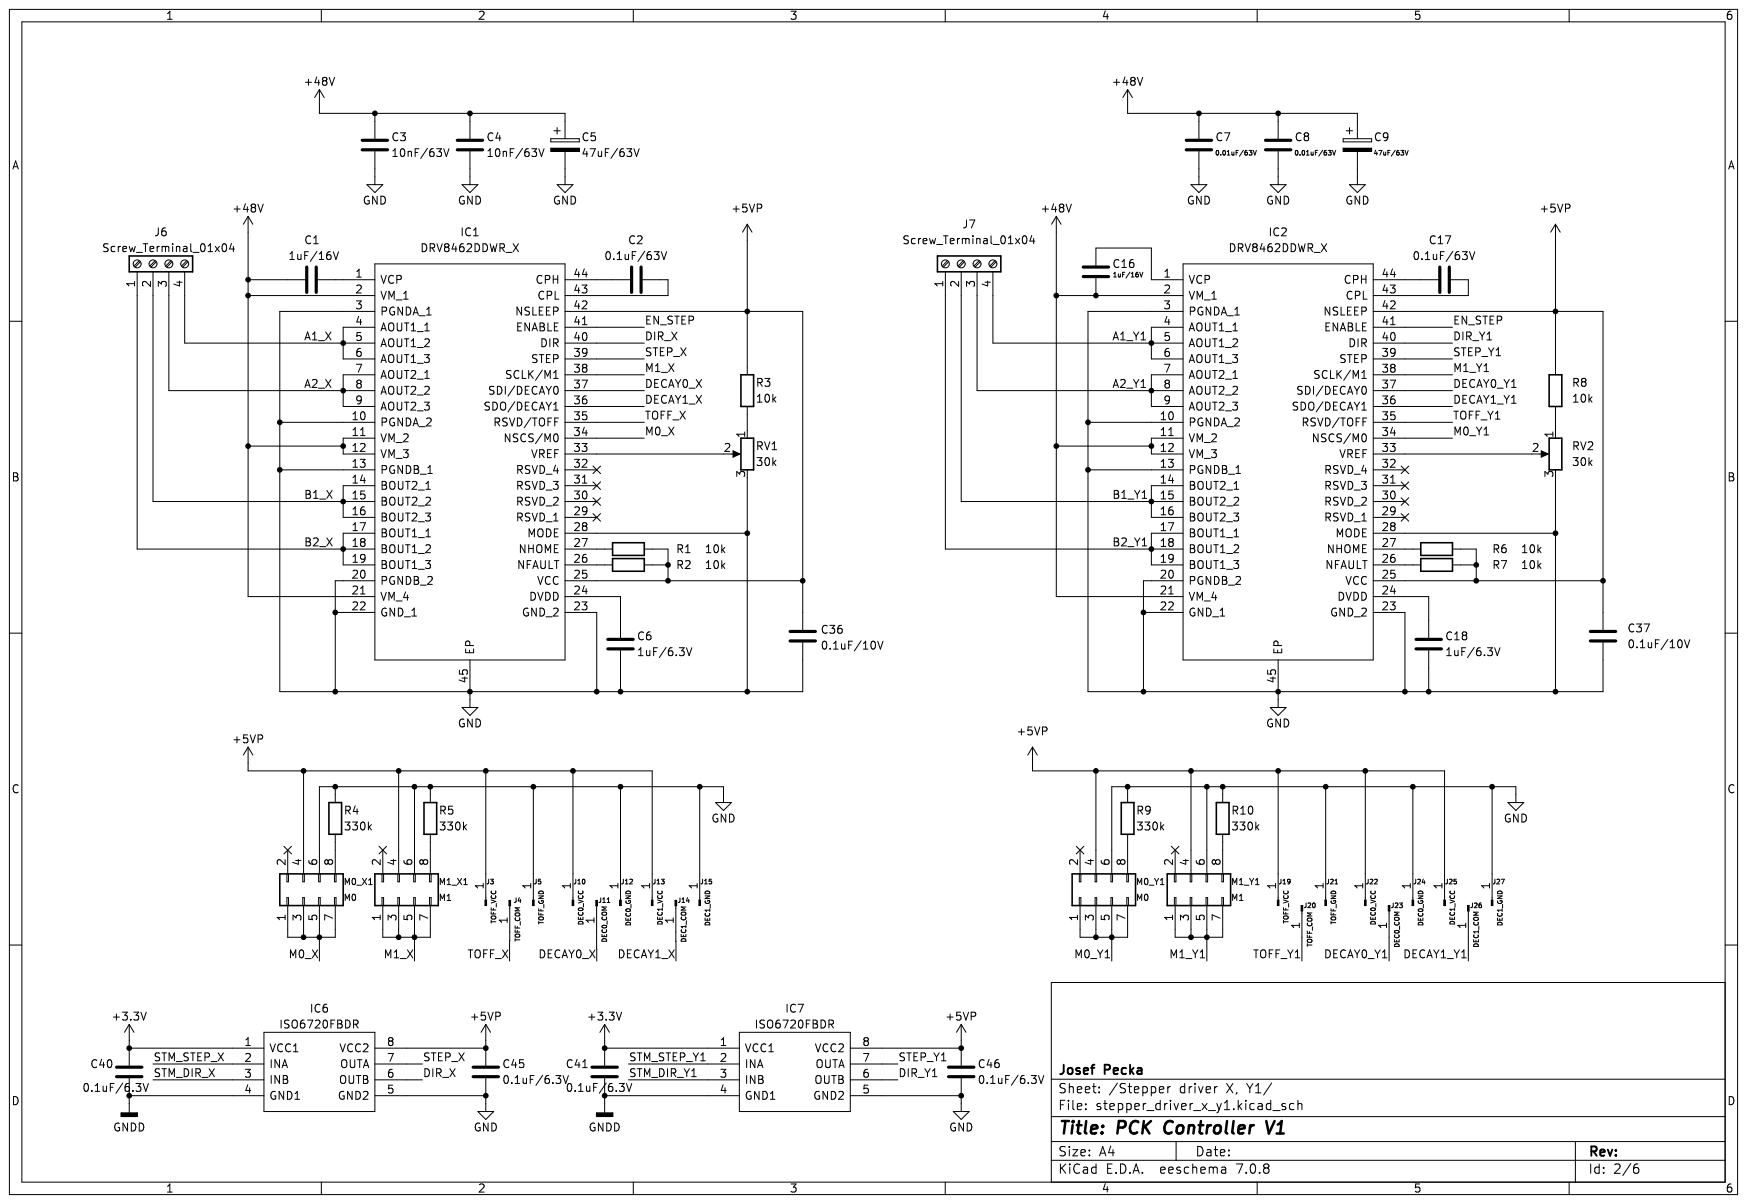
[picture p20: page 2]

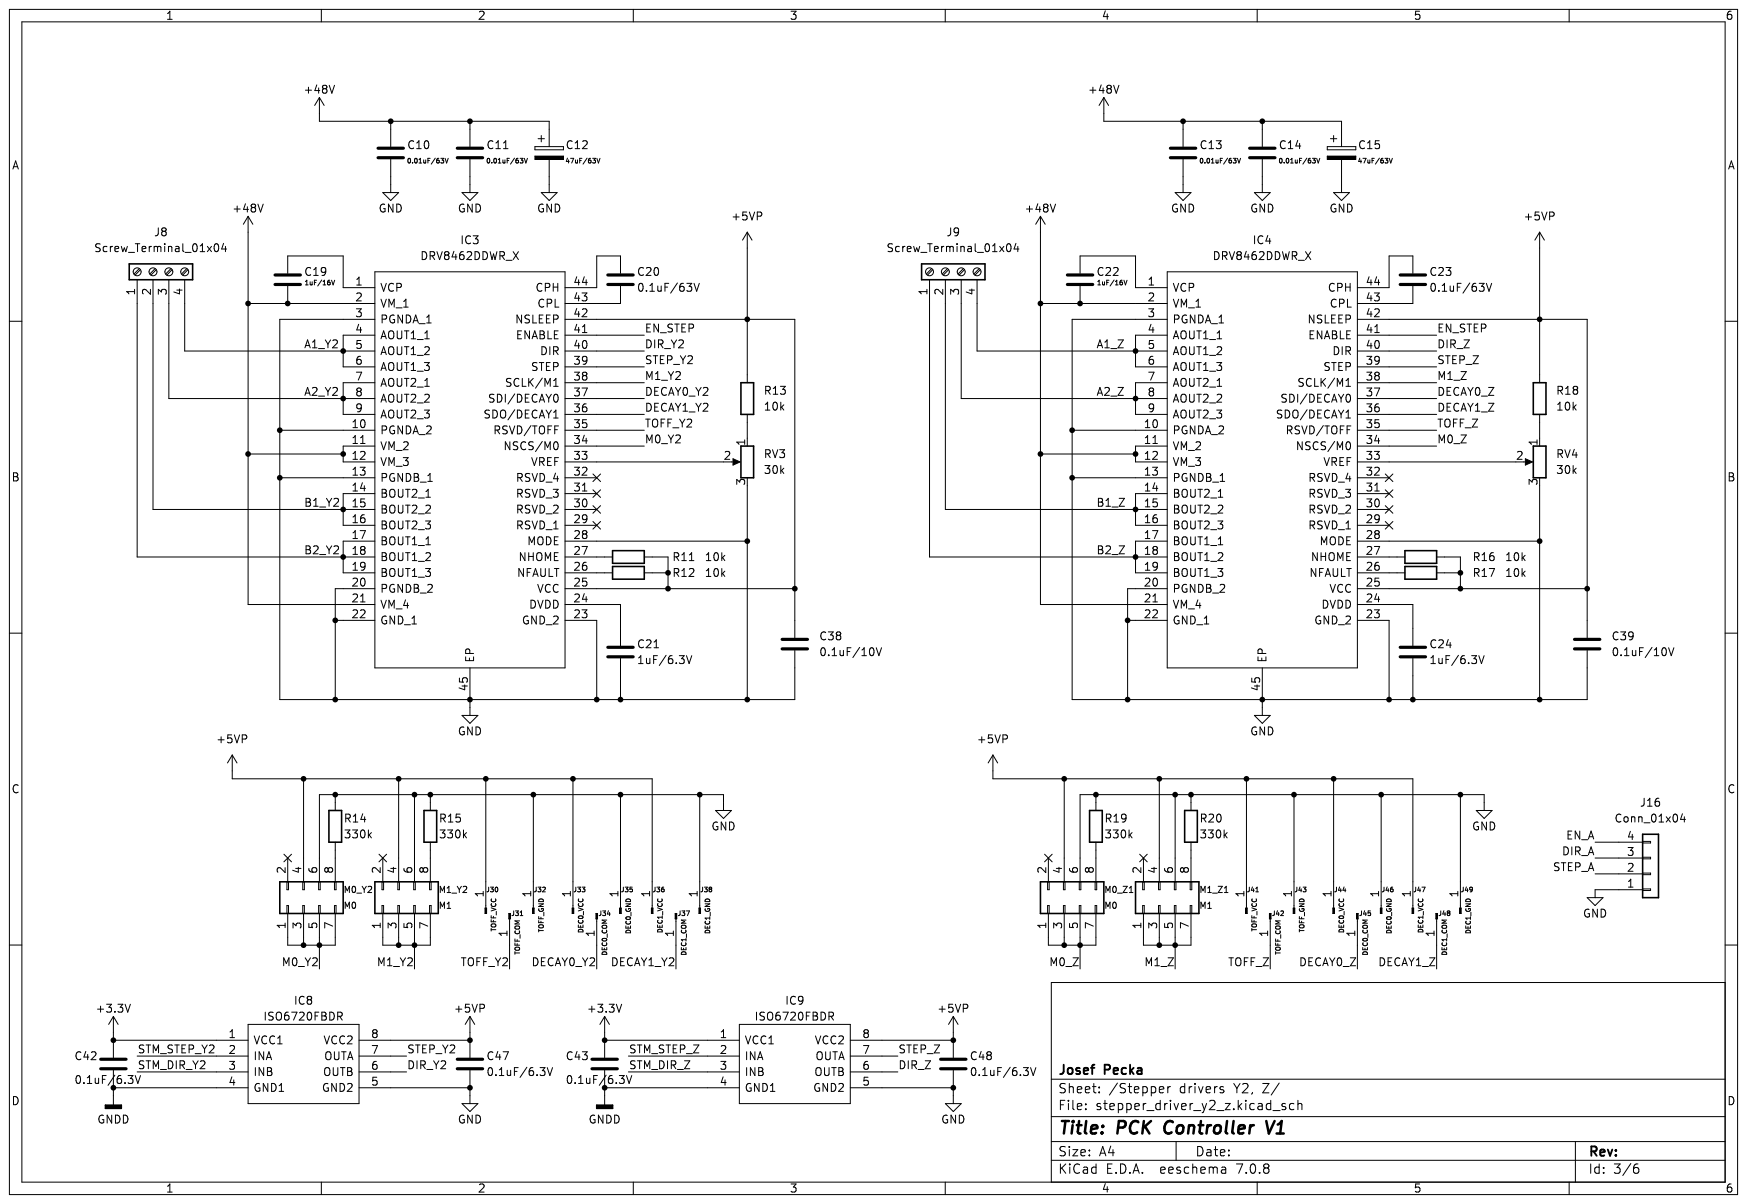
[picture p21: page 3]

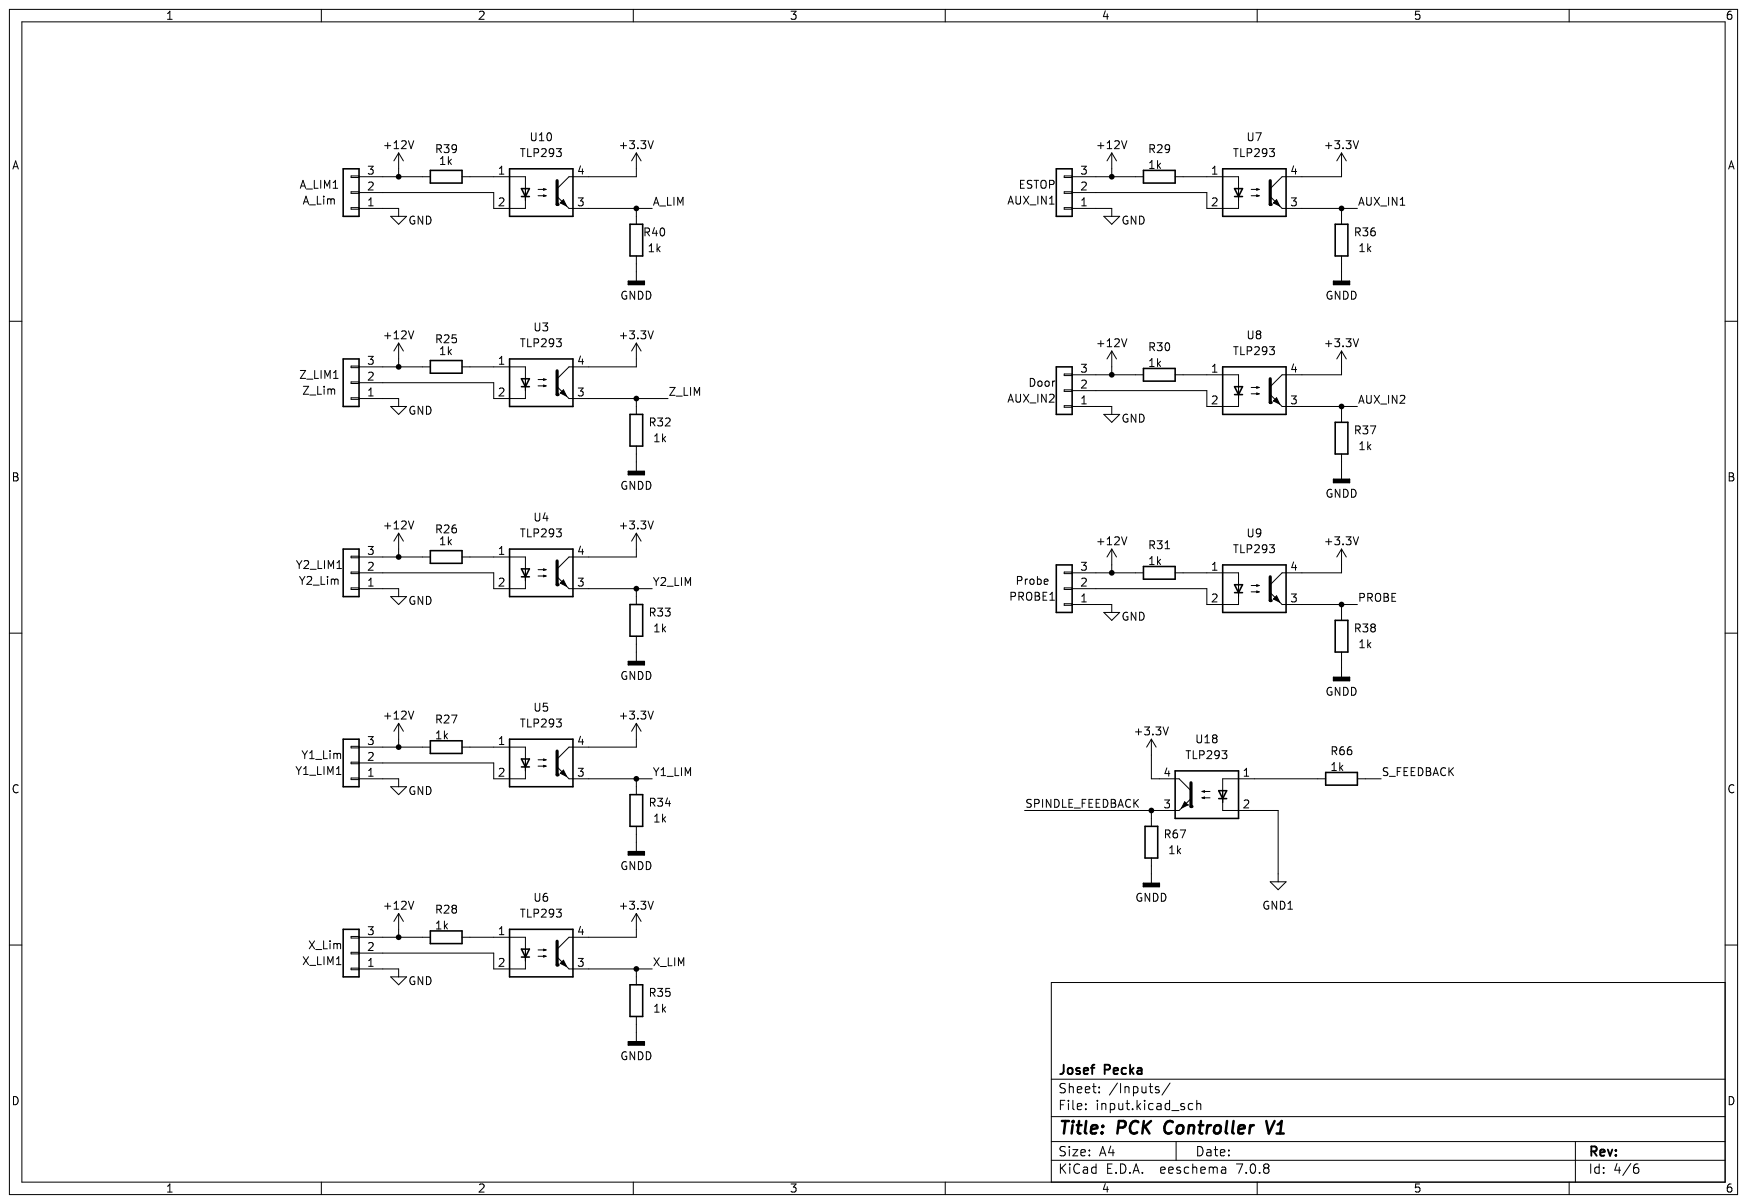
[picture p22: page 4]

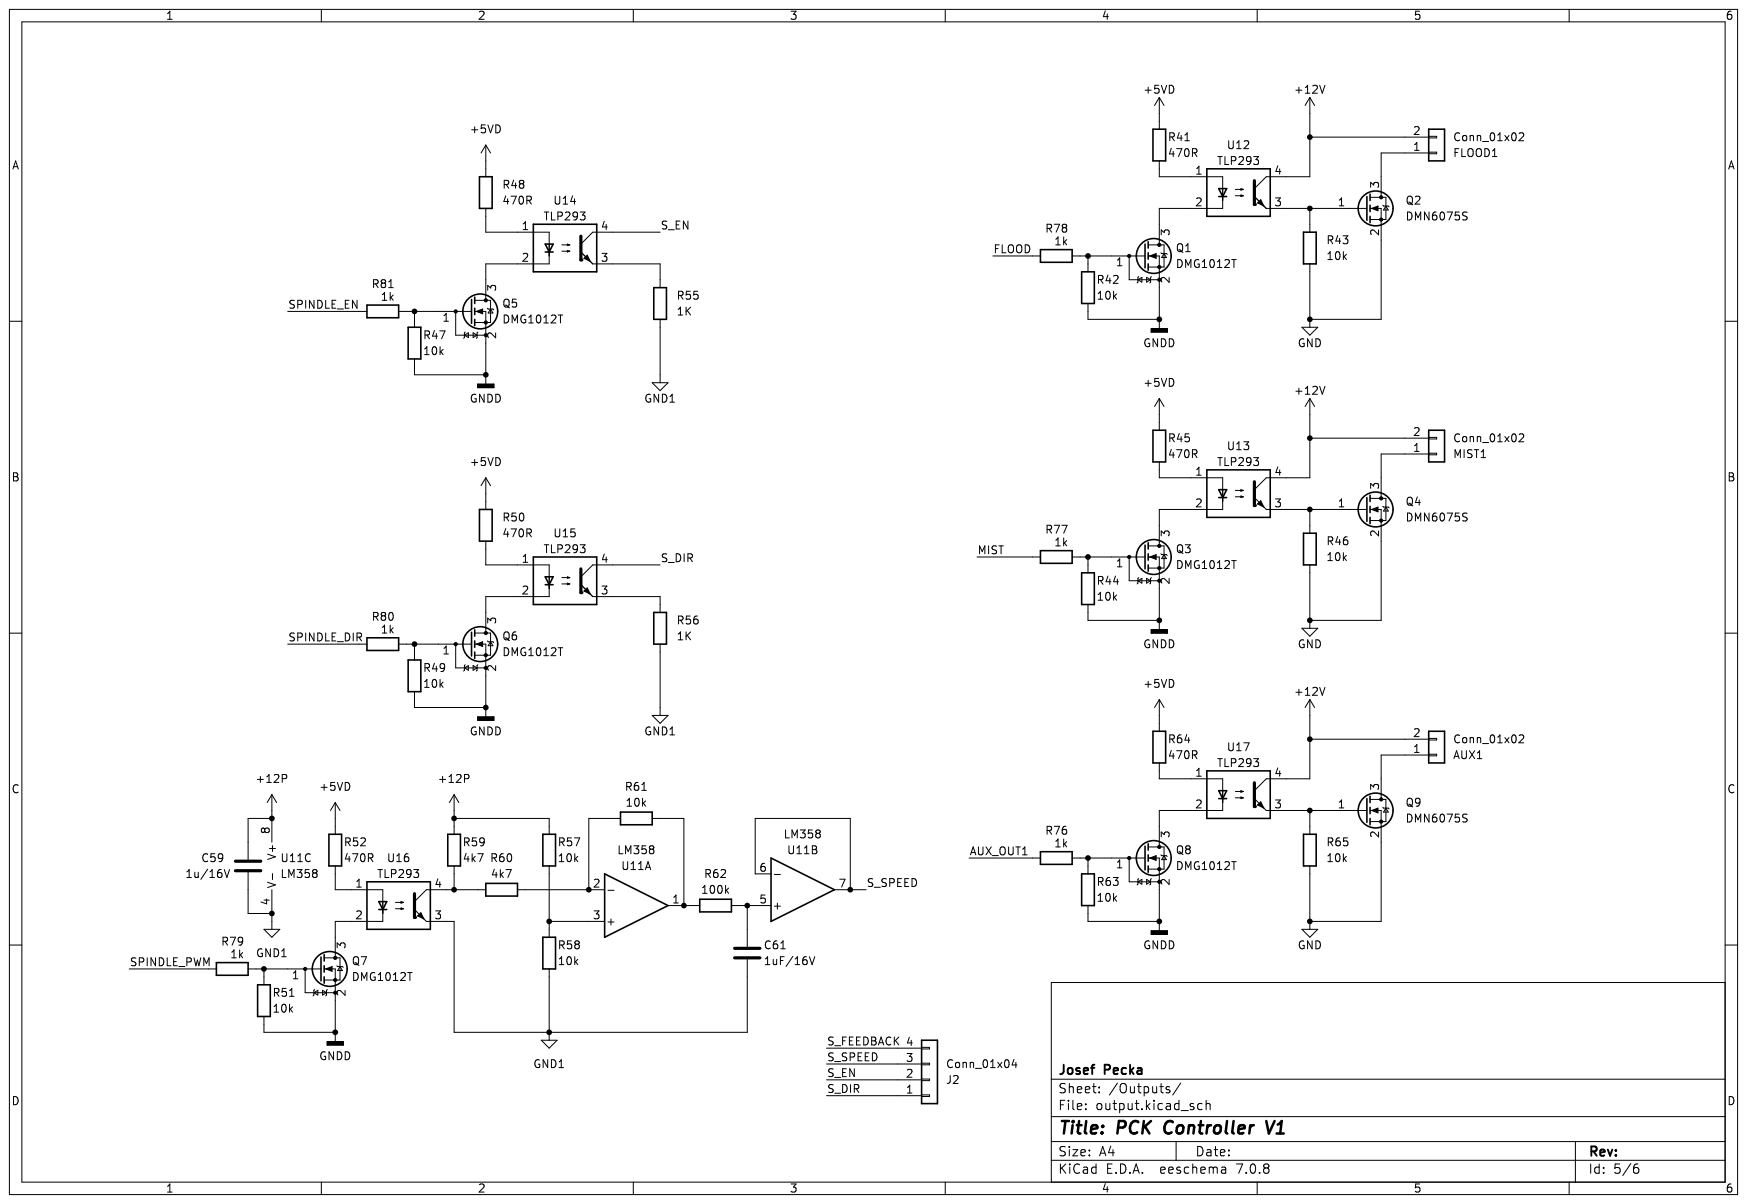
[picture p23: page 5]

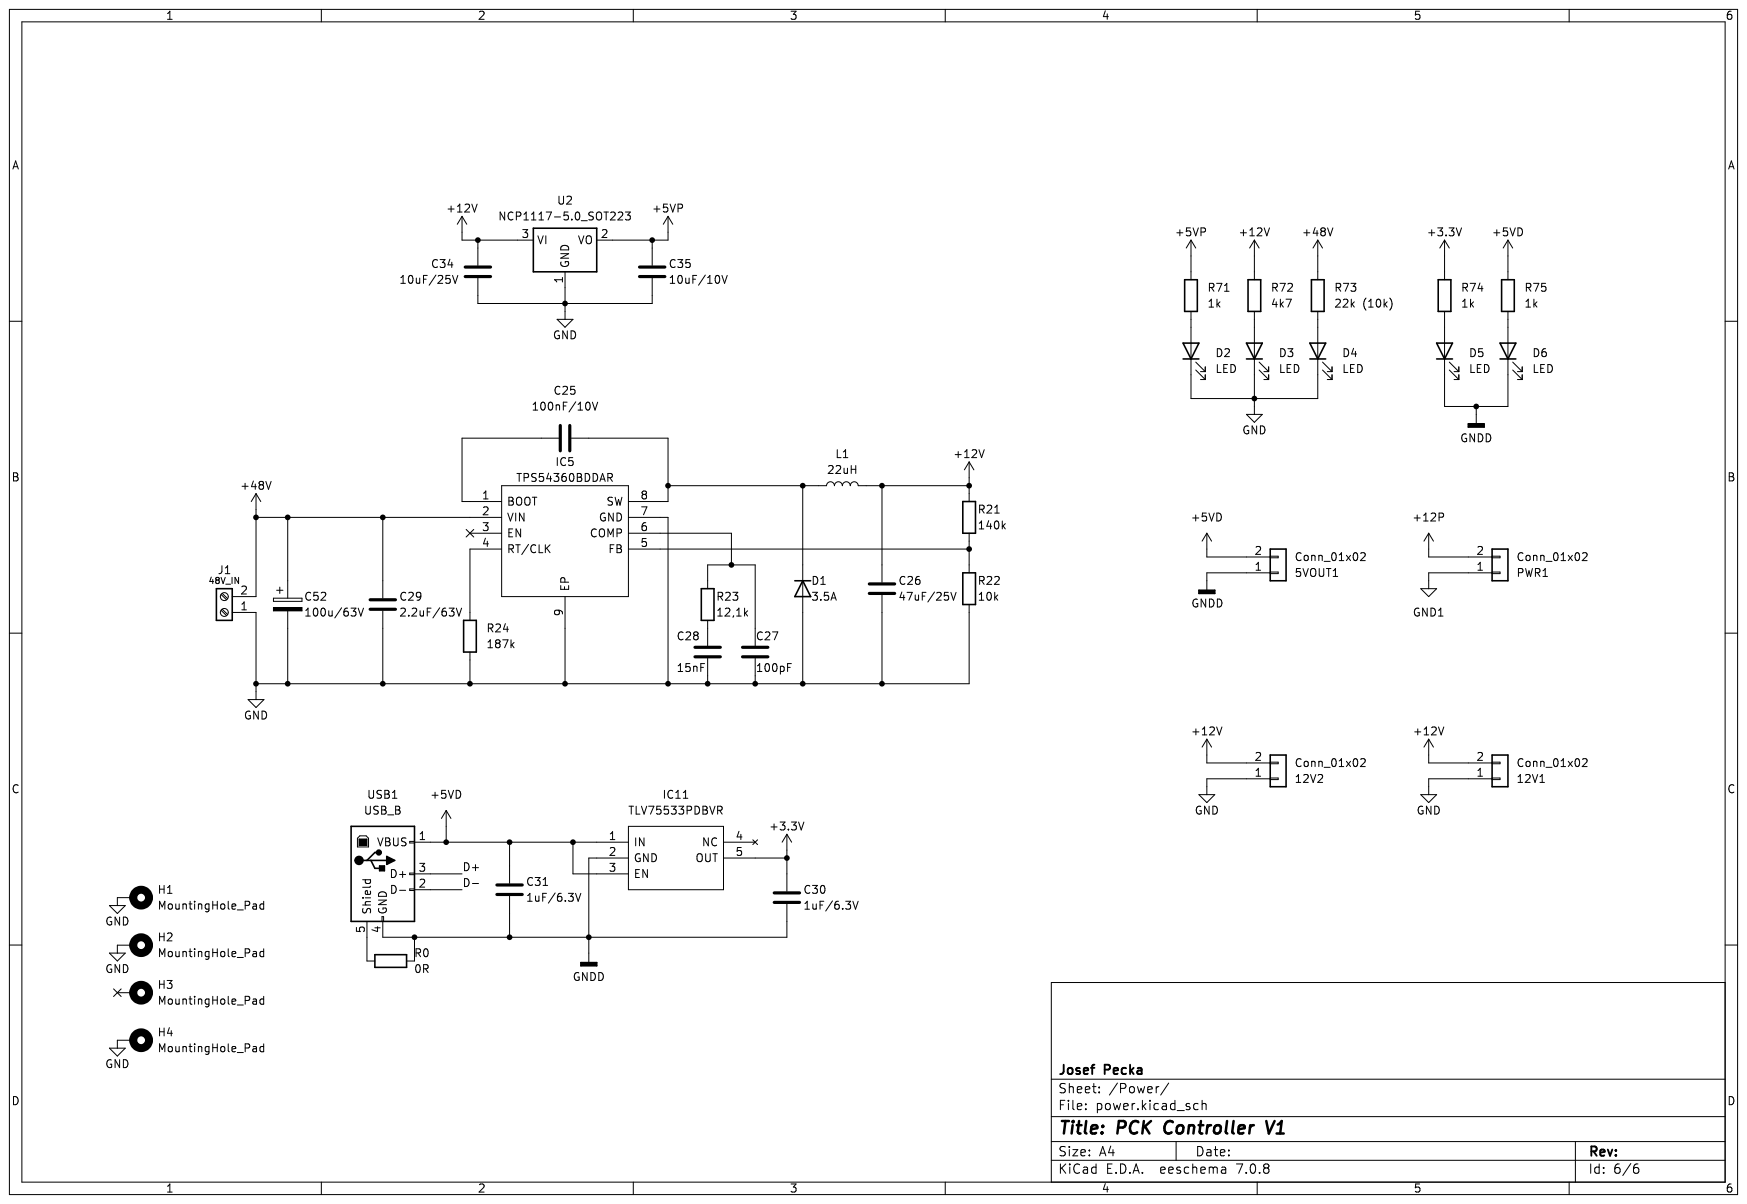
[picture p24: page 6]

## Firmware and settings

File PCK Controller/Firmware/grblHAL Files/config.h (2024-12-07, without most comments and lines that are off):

#define _GRBL_CONFIG_H_
#define N_AXIS 3 // Number of axes
#if (!defined AXIS_REMAP_ABC2UVW && (N_AXIS > 3 && N_AXIS < 7)) || defined __DOXYGEN__
#define AXIS_REMAP_ABC2UVW Off
#endif
#if !defined N_SPINDLE || defined __DOXYGEN__
#define N_SPINDLE 1
#endif
#if !defined N_SYS_SPINDLE || defined __DOXYGEN__
#define N_SYS_SPINDLE 1
#endif
#if !defined BUILD_INFO || defined __DOXYGEN__
#define BUILD_INFO ""
#endif
#if !defined COMPATIBILITY_LEVEL || defined __DOXYGEN__
#define COMPATIBILITY_LEVEL 1
#endif
#if !defined ENABLE_SPINDLE_LINEARIZATION || defined __DOXYGEN__
#define ENABLE_SPINDLE_LINEARIZATION 0  // Set to 1 to enable spindle RPM linearization. Requires compatible driver if enabled.
#endif
#if !defined SPINDLE_NPWM_PIECES || defined __DOXYGEN__
#define SPINDLE_NPWM_PIECES 4 // Number of pieces for spindle RPM linearization, max 4.
#endif
#include "nuts_bolts.h"
#if !defined MASLOW_ROUTER || defined __DOXYGEN__
#define MASLOW_ROUTER Off
#endif
#if !defined WALL_PLOTTER || defined __DOXYGEN__
#define WALL_PLOTTER Off
#endif
#if !defined DELTA_ROBOT || defined __DOXYGEN__
#define DELTA_ROBOT Off
#endif
#if DELTA_ROBOT && !defined MINIMUM_FEED_RATE
#define MINIMUM_FEED_RATE 0.1f // (radians/min)
#endif
#if !defined POLAR_ROBOT || defined __DOXYGEN__
#define POLAR_ROBOT Off
#endif
#if !defined COREXY || defined __DOXYGEN__
#define COREXY Off
#endif
#if !defined CHECK_MODE_DELAY || defined __DOXYGEN__
#define CHECK_MODE_DELAY 0 // ms
#endif
#if !defined DEBOUNCE_DELAY || defined __DOXYGEN__
#define DEBOUNCE_DELAY 40 // ms
#endif
#define ENABLE_PATH_BLENDING Off // Do NOT enable unless working on adding this feature!
#if !defined REPORT_OVERRIDE_REFRESH_BUSY_COUNT || defined __DOXYGEN__
#define REPORT_OVERRIDE_REFRESH_BUSY_COUNT 20   // (1-255)
#endif
#if !defined REPORT_OVERRIDE_REFRESH_IDLE_COUNT || defined __DOXYGEN__
#define REPORT_OVERRIDE_REFRESH_IDLE_COUNT 10   // (1-255) Must be less than or equal to the busy count
#endif
#if !defined REPORT_WCO_REFRESH_BUSY_COUNT || defined __DOXYGEN__
#define REPORT_WCO_REFRESH_BUSY_COUNT 30        // (2-255)
#endif
#if !defined REPORT_WCO_REFRESH_IDLE_COUNT || defined __DOXYGEN__
#define REPORT_WCO_REFRESH_IDLE_COUNT 10        // (2-255) Must be less than or equal to the busy count
#endif
#if !defined ACCELERATION_TICKS_PER_SECOND || defined __DOXYGEN__
#define ACCELERATION_TICKS_PER_SECOND 100
#endif
#if !defined REPORT_ECHO_LINE_RECEIVED || defined __DOXYGEN__
#define REPORT_ECHO_LINE_RECEIVED Off // Default disabled. Set to \ref On or 1 to enable.
#endif
#if !defined TOOL_LENGTH_OFFSET_AXIS || defined __DOXYGEN__
#define TOOL_LENGTH_OFFSET_AXIS -1 // Default is all axes.
#endif
#if !defined MINIMUM_JUNCTION_SPEED || defined __DOXYGEN__
#define MINIMUM_JUNCTION_SPEED 0.0f // (mm/min)
#endif
#if !defined MINIMUM_FEED_RATE || defined __DOXYGEN__
#define MINIMUM_FEED_RATE 1.0f // (mm/min)
#endif
#if !defined N_ARC_CORRECTION || defined __DOXYGEN__
#define N_ARC_CORRECTION 12 // Integer (1-255)
#endif
#if !defined ARC_ANGULAR_TRAVEL_EPSILON || defined __DOXYGEN__
#define ARC_ANGULAR_TRAVEL_EPSILON 5E-7f // Float (radians)
#endif
#if !defined BEZIER_MIN_STEP || defined __DOXYGEN__
#define BEZIER_MIN_STEP 0.002f
#endif
#if !defined BEZIER_MAX_STEP || defined __DOXYGEN__
#define BEZIER_MAX_STEP 0.1f
#endif
#if !defined BEZIER_SIGMA || defined __DOXYGEN__
#define BEZIER_SIGMA 0.1f
#endif
#if !defined DWELL_TIME_STEP || defined __DOXYGEN__
#define DWELL_TIME_STEP 50 // Integer (1-255) (milliseconds)
#endif
#if !defined SEGMENT_BUFFER_SIZE || defined __DOXYGEN__
#define SEGMENT_BUFFER_SIZE 10 // Uncomment to override default in stepper.h.
#endif
#if !defined SET_CHECK_MODE_PROBE_TO_START || defined __DOXYGEN__
#define SET_CHECK_MODE_PROBE_TO_START Off // Default disabled. Set to \ref On or 1 to enable.
#endif
#if !defined HARD_LIMIT_FORCE_STATE_CHECK || defined __DOXYGEN__
#define HARD_LIMIT_FORCE_STATE_CHECK Off // Default disabled. Set to \ref On or 1 to enable.
#endif
#if !defined HOMING_AXIS_SEARCH_SCALAR || defined __DOXYGEN__
#define HOMING_AXIS_SEARCH_SCALAR  1.5f // Must be > 1 to ensure limit switch will be engaged.
#endif
#if !defined HOMING_AXIS_LOCATE_SCALAR || defined __DOXYGEN__
#define HOMING_AXIS_LOCATE_SCALAR  10.0f// Must be > 1 to ensure limit switch is cleared.
#endif
#if !defined ENABLE_RESTORE_NVS_WIPE_ALL || defined __DOXYGEN__
#define ENABLE_RESTORE_NVS_WIPE_ALL On //!< `$RST=*` Default enabled. Set to \ref Off or 0 to disable.
#endif
#if !defined ENABLE_RESTORE_NVS_DEFAULT_SETTINGS || defined __DOXYGEN__
#define ENABLE_RESTORE_NVS_DEFAULT_SETTINGS On //!< `$RST=$`  Default enabled. Set to \ref Off or 0 to disable.
#endif
#if !defined ENABLE_RESTORE_NVS_CLEAR_PARAMETERS || defined __DOXYGEN__
#define ENABLE_RESTORE_NVS_CLEAR_PARAMETERS On //!< `$RST=#`  Default enabled. Set to \ref Off or 0 to disable.
#endif
#if !defined ENABLE_RESTORE_NVS_DRIVER_PARAMETERS || defined __DOXYGEN__
#define ENABLE_RESTORE_NVS_DRIVER_PARAMETERS On //!< `$RST=&` Default enabled. Set to \ref Off or 0 to disable. For drivers that implements non-generic settings.
#endif
#if !defined SETTINGS_RESTORE_DEFAULTS || defined __DOXYGEN__
#define SETTINGS_RESTORE_DEFAULTS On //!< Default enabled. Set to \ref Off or 0 to disable.
#endif
#if !defined SETTINGS_RESTORE_PARAMETERS || defined __DOXYGEN__
#define SETTINGS_RESTORE_PARAMETERS On //!< Default enabled. Set to \ref Off or 0 to disable.
#endif
#if !defined SETTINGS_RESTORE_STARTUP_LINES || defined __DOXYGEN__
#define SETTINGS_RESTORE_STARTUP_LINES On //!< Default enabled. Set to \ref Off or 0 to disable.
#endif
#if !defined SETTINGS_RESTORE_BUILD_INFO || defined __DOXYGEN__
#define SETTINGS_RESTORE_BUILD_INFO  On //!< Default enabled. Set to \ref Off or 0 to disable.
#endif
#if !defined SETTINGS_RESTORE_DRIVER_PARAMETERS || defined __DOXYGEN__
#define SETTINGS_RESTORE_DRIVER_PARAMETERS On //!< Default enabled. Set to \ref Off or 0 to disable.
#endif
#if !defined DISABLE_BUILD_INFO_WRITE_COMMAND || defined __DOXYGEN__
#define DISABLE_BUILD_INFO_WRITE_COMMAND Off //!< `$I=` Default enabled. Uncomment to disable.
#endif
#if !defined SLEEP_DURATION || defined __DOXYGEN__
#define SLEEP_DURATION 5.0f // Number of minutes before sleep mode is entered.
#endif
#if !defined NVSDATA_BUFFER_ENABLE || defined __DOXYGEN__
#define NVSDATA_BUFFER_ENABLE On // Default on, set to \ref off or 0 to disable.
#endif
#if !defined TOOLSETTER_RADIUS || defined __DOXYGEN__
#define TOOLSETTER_RADIUS 5.0f
#endif
#if !defined ENABLE_BACKLASH_COMPENSATION || defined __DOXYGEN__
#define ENABLE_BACKLASH_COMPENSATION Off
#endif
#if COMPATIBILITY_LEVEL == 0 || defined __DOXYGEN__
#if !defined N_TOOLS || defined __DOXYGEN__
#define N_TOOLS 0
#endif
#endif
#if !defined NGC_EXPRESSIONS_ENABLE || defined __DOXYGEN__
#define NGC_EXPRESSIONS_ENABLE Off
#endif
#if (NGC_EXPRESSIONS_ENABLE && !defined NGC_N_ASSIGN_PARAMETERS_PER_BLOCK) || defined __DOXYGEN__
#define NGC_N_ASSIGN_PARAMETERS_PER_BLOCK 10
#endif
#if !defined LATHE_UVW_OPTION || defined __DOXYGEN__
#define LATHE_UVW_OPTION Off
#endif
#if !defined DEFAULT_REPORT_MACHINE_POSITION || defined __DOXYGEN__
#define DEFAULT_REPORT_MACHINE_POSITION On // Default on. Set to \ref Off or 0 to disable.
#endif
#if !defined DEFAULT_REPORT_BUFFER_STATE || defined __DOXYGEN__
#define DEFAULT_REPORT_BUFFER_STATE On // Default on. Set to \ref Off or 0 to disable.
#endif
#if !defined DEFAULT_REPORT_LINE_NUMBERS || defined __DOXYGEN__
#define DEFAULT_REPORT_LINE_NUMBERS On // Default on. Set to \ref Off or 0 to disable.
#endif
#if !defined DEFAULT_REPORT_CURRENT_FEED_SPEED || defined __DOXYGEN__
#define DEFAULT_REPORT_CURRENT_FEED_SPEED On // Default on. Set to \ref Off or 0 to disable.
#endif
#if !defined DEFAULT_REPORT_PIN_STATE || defined __DOXYGEN__
#define DEFAULT_REPORT_PIN_STATE On // Default on. Set to \ref Off or 0 to disable.
#endif
#if !defined DEFAULT_REPORT_WORK_COORD_OFFSET || defined __DOXYGEN__
#define DEFAULT_REPORT_WORK_COORD_OFFSET On // Default on. Set to \ref Off or 0 to disable.
#endif
#if !defined DEFAULT_REPORT_OVERRIDES || defined __DOXYGEN__
#define DEFAULT_REPORT_OVERRIDES On // Default on. Set to \ref Off or 0 to disable.
#endif
#if !defined DEFAULT_REPORT_PROBE_COORDINATES || defined __DOXYGEN__
#define DEFAULT_REPORT_PROBE_COORDINATES On // Default on. Set to \ref Off or 0 to disable.
#endif
#if !defined DEFAULT_REPORT_SYNC_ON_WCO_CHANGE || defined __DOXYGEN__
#define DEFAULT_REPORT_SYNC_ON_WCO_CHANGE On //!< ok
#endif
#if !defined DEFAULT_REPORT_PARSER_STATE || defined __DOXYGEN__
#define DEFAULT_REPORT_PARSER_STATE Off // Default off. Set to \ref On or 1 to enable.
#endif
#if !defined DEFAULT_REPORT_ALARM_SUBSTATE || defined __DOXYGEN__
#define DEFAULT_REPORT_ALARM_SUBSTATE Off // Default off. Set to \ref On or 1 to enable.
#endif
#if !defined DEFAULT_REPORT_RUN_SUBSTATE || defined __DOXYGEN__
#define DEFAULT_REPORT_RUN_SUBSTATE Off // Default off. Set to \ref On or 1 to enable.
#endif
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

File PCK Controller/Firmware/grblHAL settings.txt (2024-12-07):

$0 = 10.0    (Step pulse time, microseconds)
$1 = 25    (Step idle delay, milliseconds)
$2 = 0    (Step pulse invert, mask)
$3 = 3    (Step direction invert, mask)
$4 = 0    (Invert step enable pin, boolean)
$5 = 7    (Invert limit pins, boolean)
$8 = 0   
$9 = 1   
$10 = 511    (Status report options, mask)
$11 = 0.010    (Junction deviation, millimeters)
$12 = 0.002    (Arc tolerance, millimeters)
$13 = 0    (Report in inches, boolean)
$14 = 0   
$15 = 0   
$16 = 0   
$17 = 0   
$18 = 0   
$20 = 0    (Soft limits enable, boolean)
$21 = 1    (Hard limits enable, boolean)
$22 = 1    (Homing cycle enable, boolean)
$23 = 0    (Homing direction invert, mask)
$24 = 250.0    (Homing locate feed rate, mm/min)
$25 = 2000.0    (Homing search seek rate, mm/min)
$26 = 250    (Homing switch debounce delay, milliseconds)
$27 = 2.000    (Homing switch pull-off distance, millimeters)
$28 = 0.100   
$29 = 0.0   
$30 = 20000.000    (Maximum spindle speed, RPM)
$31 = 1700.000    (Minimum spindle speed, RPM)
$32 = 0    (Laser-mode enable, boolean)
$33 = 1000.0   
$34 = 0.0   
$35 = 0.0   
$36 = 100.0   
$37 = 0   
$39 = 1   
$40 = 0   
$43 = 1   
$44 = 4   
$45 = 3   
$46 = 0   
$62 = 0   
$63 = 3   
$64 = 0   
$100 = 1600.00000    (X-axis travel resolution, step/mm)
$101 = 1371.42858    (Y-axis travel resolution, step/mm)
$102 = 9600.00000    (Z-axis travel resolution, step/mm)
$110 = 3000.000    (X-axis maximum rate, mm/min)
$111 = 3000.000    (Y-axis maximum rate, mm/min)
$112 = 500.000    (Z-axis maximum rate, mm/min)
$120 = 75.000    (X-axis acceleration, mm/sec^2)
$121 = 75.000    (Y-axis acceleration, mm/sec^2)
$122 = 30.000    (Z-axis acceleration, mm/sec^2)
$130 = 450.000    (X-axis maximum travel, millimeters)
$131 = 750.000    (Y-axis maximum travel, millimeters)
$132 = 110.000    (Z-axis maximum travel, millimeters)
$341 = 0   
$342 = 30.0   
$343 = 25.0   
$344 = 200.0   
$345 = 200.0   
$346 = 1   
$372 = 0   
$384 = 0   
$398 = 100   
$481 = 0   
$484 = 1   
$486 = 0 

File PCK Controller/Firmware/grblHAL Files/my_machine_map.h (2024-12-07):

/*
  my_machine_map.h - driver code for STM32F4xx ARM processors

  Part of grblHAL

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
  You should have received a copy of the GNU General Public License
  along with Grbl.  If not, see <http://www.gnu.org/licenses/>.
*/

#if N_ABC_MOTORS > 2
#error "Axis configuration is not supported!"
#endif


#if TRINAMIC_ENABLE
#error "Trinamic plugin not supported!"
#endif

#if !defined(STM32F446xx) || HSE_VALUE != 25000000
#error "This board has STM32F446 processor with a 25MHz crystal, select a corresponding build!"
#endif

#define BOARD_NAME "PCK Controller"
//#define BOARD_URL ""

//#define SERIAL_PORT     1   // GPIOA: TX =  9, RX = 10
//#define SERIAL1_PORT   31   // GPIOC: TX = 10, RX = 11
//#define I2C_ENABLE      1
//#define I2C_FASTMODE
//#define HAS_IOPORTS


// Define step pulse output pins.
#define X_STEP_PORT             GPIOC
#define X_STEP_PIN              9
#define Y_STEP_PORT             GPIOC
#define Y_STEP_PIN              7
#define Z_STEP_PORT             GPIOB
#define Z_STEP_PIN              13
#define STEP_OUTMODE            GPIO_BITBAND
//#define STEP_PINMODE            PINMODE_OD // Uncomment for open drain outputs

// Define step direction output pins.
#define X_DIRECTION_PORT        GPIOC
#define X_DIRECTION_PIN         8
#define Y_DIRECTION_PORT        GPIOC
#define Y_DIRECTION_PIN         6
#define Z_DIRECTION_PORT        GPIOB
#define Z_DIRECTION_PIN         12
#define DIRECTION_OUTMODE       GPIO_BITBAND
//#define DIRECTION_PINMODE       PINMODE_OD // Uncomment for open drain outputs

// Define stepper driver enable/disable output pin.
#define X_ENABLE_PORT               GPIOA
#define X_ENABLE_PIN                8
#define Y_ENABLE_PORT               GPIOA
#define Y_ENABLE_PIN                8
#define Z_ENABLE_PORT               GPIOA
#define Z_ENABLE_PIN                8
//#define STEPPERS_ENABLE_PORT       GPIOA
//#define STEPPERS_ENABLE_PIN        8
#define STEPPERS_ENABLE_OUTMODE    GPIO_BITBAND

// Define homing/hard limit switch input pins.
#define X_LIMIT_PORT            GPIOB
#define X_LIMIT_PIN             2
#define Y_LIMIT_PORT            GPIOB
#define Y_LIMIT_PIN             1
#define Z_LIMIT_PORT            GPIOC
#define Z_LIMIT_PIN             5
#define LIMIT_INMODE            GPIO_BITBAND

// Define ganged axis or A axis step pulse and step direction output pins.
#if N_ABC_MOTORS > 0
#define M3_AVAILABLE
#define M3_STEP_PORT            GPIOB
#define M3_STEP_PIN             15
#define M3_DIRECTION_PORT       GPIOB
#define M3_DIRECTION_PIN        14
#define M3_LIMIT_PORT           GPIOB
#define M3_LIMIT_PIN            0
#define M3_ENABLE_PORT          GPIOA
#define M3_ENABLE_PIN           8
#endif

// Define ganged axis or A axis step pulse and step direction output pins.
#if N_ABC_MOTORS == 2
#define M4_AVAILABLE
#define M4_STEP_PORT            GPIOA
#define M4_STEP_PIN             10
#define M4_DIRECTION_PORT       GPIOA
#define M4_DIRECTION_PIN        13
#define M4_LIMIT_PORT           GPIOB
#define M4_LIMIT_PIN            10
#define M4_ENABLE_PORT          GPIOA
#define M4_ENABLE_PIN           9
#endif

// Define spindle enable and spindle direction output pins.
#define SPINDLE_ENABLE_PORT     GPIOC
#define SPINDLE_ENABLE_PIN      2
#define SPINDLE_DIRECTION_PORT  GPIOC
#define SPINDLE_DIRECTION_PIN   3
#define SPINDLE_OUTMODE         GPIO_BITBAND

// Define spindle PWM output pin.
#define SPINDLE_PWM_PORT_BASE   GPIOA_BASE
#define SPINDLE_PWM_PIN         5

// Define flood and mist coolant enable output pins.
#define COOLANT_FLOOD_PORT      GPIOA
#define COOLANT_FLOOD_PIN       1
#define COOLANT_MIST_PORT       GPIOA
#define COOLANT_MIST_PIN        0
#define COOLANT_OUTMODE         GPIO_BITBAND

#define AUXOUTPUT0_PORT         GPIOA
#define AUXOUTPUT0_PIN          2
//#define AUXOUTPUT1_PORT         GPIOB
//#define AUXOUTPUT1_PIN          0
//#define AUXOUTPUT2_PORT         GPIOA
//#define AUXOUTPUT2_PIN          4
//#define AUXOUTPUT3_PORT         GPIOA
//#define AUXOUTPUT3_PIN          6
#define AUXOUTPUT_OUTMODE       GPIO_BITBAND

//#define AUXINPUT0_PORT          GPIOA
//#define AUXINPUT0_PIN           0
//#define AUXINPUT1_PORT          GPIOA
//#define AUXINPUT1_PIN           1
//#define AUXINPUT2_PORT          GPIOA
//#define AUXINPUT2_PIN           2


// Define user-control controls (cycle start, reset, feed hold) input pins.
#define RESET_PORT              GPIOA
#define RESET_PIN               15
#define FEED_HOLD_PORT          GPIOB
#define FEED_HOLD_PIN           8
#define CYCLE_START_PORT        GPIOB
#define CYCLE_START_PIN         9
#if SAFETY_DOOR_ENABLE
#define SAFETY_DOOR_PORT        GPIOC
#define SAFETY_DOOR_PIN         4
#endif
#define CONTROL_INMODE          GPIO_BITBAND

// Define probe switch input pin.
#define PROBE_PORT              GPIOC
#define PROBE_PIN               4

#if I2C_STROBE_ENABLE
#define I2C_STROBE_PORT         GPIOB
#define I2C_STROBE_PIN          10
#endif

#if SDCARD_ENABLE
#define SD_CS_PORT              GPIOA
#define SD_CS_PIN               3
#define SPI_PORT                12 // GPIOB, SCK = 3, MISO = 4, MOSI = 5
#endif

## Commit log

2024-11-16 Acrylic sheets files added
    [Acrylic sheet REAR.dxf, Acrylic sheet REAR.f3d, Acrylic sheet REAR.step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]
2024-11-16 Aluminum parts files added
    [Base mount FRONT.f3d, Base mount FRONT.step, Base mount REAR.f3d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]
2024-11-16 DXF Files
    [Acrylic sheet REAR.dxf, Acrylic sheet SIDE.dxf]
2024-11-16 Base mount FRONT Updated
    [Base mount FRONT.f3d]
2024-11-17 3D Print files added
    [Base mount FRONT L.3mf, Base mount FRONT L.f3d, Base mount FRONT L.step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]
2024-11-19 PCK CNC BOM added
    [PCK CNC - BOM.xlsx]
2024-11-22 Z Axis cover updated
    [Electronics panel connector A.3mf, Electronics panel connector B.3mf, Electronics panel connector C.3mf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]
2024-11-22 Added BOM in PDF
    [PCK CNC - BOM.xlsx]
2024-11-22 Updated BOMs
    [PCK CNC - BOM.xlsx]
2024-11-23 Updated Spindle mount plate
    [Spindle mount plate.f3d, Spindle mount plate.step]
2024-11-23 Updated Y Axis motor mounts
    [Y Axis motor mount LEFT.f3d, Y Axis motor mount LEFT.step, Y Axis motor mount RIGHT.f3d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]
2024-11-23 Added PCK Controller - BOM
    [PCK Controller - BOM.xlsx]
2024-11-23 Added PCK Controller files
    [PCK-Controller-B_Cu.gbl, PCK-Controller-B_Mask.gbs, PCK-Controller-B_Paste.gbp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]
2024-12-07 Added FW Files
    [config.h, grblHAL settings.txt]
2024-12-07 BOMs Updated
    [PCK CNC - BOM.xlsx]
2024-12-17 Updated X Axis plates
    [X Axis plate LEFT.f3d, X Axis plate LEFT.step, X Axis plate RIGHT.f3d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]
2025-01-04 Updated BOM
    [PCK CNC - BOM.xlsx]
2025-01-23 Update electronics cover files
    [Electronics panel LEFT.3mf, Electronics panel LEFT.f3d, Electronics panel LEFT.step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]
2025-01-26 Added PCK CNC assembly instructions
2025-01-26 Added drawings fro tapping threads
2025-01-29 Updated assembly instructions
2025-01-29 Updated PCK-CNC BOMs to match Assembly instructions
    [PCK CNC - BOM.xlsx]
2025-02-20 Updated schematics
    [PCK-Controller-B_Cu.gbl, PCK-Controller-B_Mask.gbs, PCK-Controller-B_Paste.gbp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]

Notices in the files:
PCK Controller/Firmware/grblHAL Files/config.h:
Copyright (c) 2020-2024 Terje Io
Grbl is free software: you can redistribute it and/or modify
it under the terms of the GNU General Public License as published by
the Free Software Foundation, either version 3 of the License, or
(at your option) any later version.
